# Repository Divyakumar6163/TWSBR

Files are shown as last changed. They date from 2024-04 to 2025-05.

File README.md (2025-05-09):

# Robofest 4.0 - Two Wheeled Self Balancing Robot

## Overview

This repository contains all the documentation, design files, and implementation details of a **Two-Wheeled Self-Balancing Robot** developed by students of **IIT Bhubaneswar** as part of **Robofest 4.0**.

The robot operates on the principle of an **inverted pendulum**, achieving dynamic stability using sensors, real-time data processing, and a PID control system. It combines **self-balancing** capabilities with **line-following** functionality, and features a **payload-carrying structure**.

## Table of Contents

* [Overview](#overview)
* [Robot Description](#robot-description)
* [Salient Features](#salient-features)
* [Mechanical Design](#mechanical-design)
* [Electronics and Control](#electronics-and-control)
* [Softwares Used](#softwares-used)
* [Block Diagrams](#block-diagrams)
* [Applications](#applications)
* [Team](#team)

## Robot Description

The robot uses two NEMA 23 stepper motors driven by a PID controller implemented on an **Arduino Nano**. An **MPU-6050** sensor detects the tilt and angular velocity. The robot balances itself by calculating real-time error values and adjusting motor outputs accordingly.

## Salient Features

* **Self-Balancing** using MPU-6050 and PID control
* **Payload capacity** of \~1kg
* **Line-following** using IR sensors
* **Adjustable height** using threaded rods
* **Symmetric aluminum frame** for better stability

## Mechanical Design

* 3-layer structure with aluminum plates (Top, Middle, Bottom)
* Fully threaded rods for height adjustment
* Custom motor mount flanges
* Center of gravity optimized for balance

## Electronics and Control

* **Microcontroller**: Arduino Nano
* **Sensors**: MPU-6050, IR Sensors
* **Actuators**: NEMA 23/17 Stepper Motors with TB6600/A4988 drivers
* **Protection**: Diodes, resistors, and capacitors for circuit stability

## Softwares Used

* **Arduino IDE**: PID logic, sensor reading, and motor control
* **SolidWorks**: CAD design of chassis
* **MATLAB**: PID tuning and simulation
* **KiCad & Fritzing**: PCB and circuit design
* **VS Code (Python + OpenCV)**: Code Editor
* **ANSYS**: Stress and vibration analysis

## Block Diagrams

#### Electronics Block Diagram
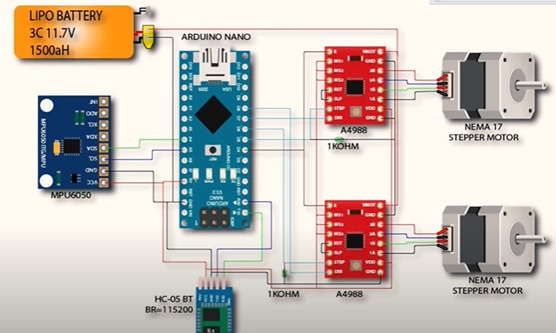
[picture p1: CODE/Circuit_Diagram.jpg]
Electronics Block Diagram


#### Flowchart
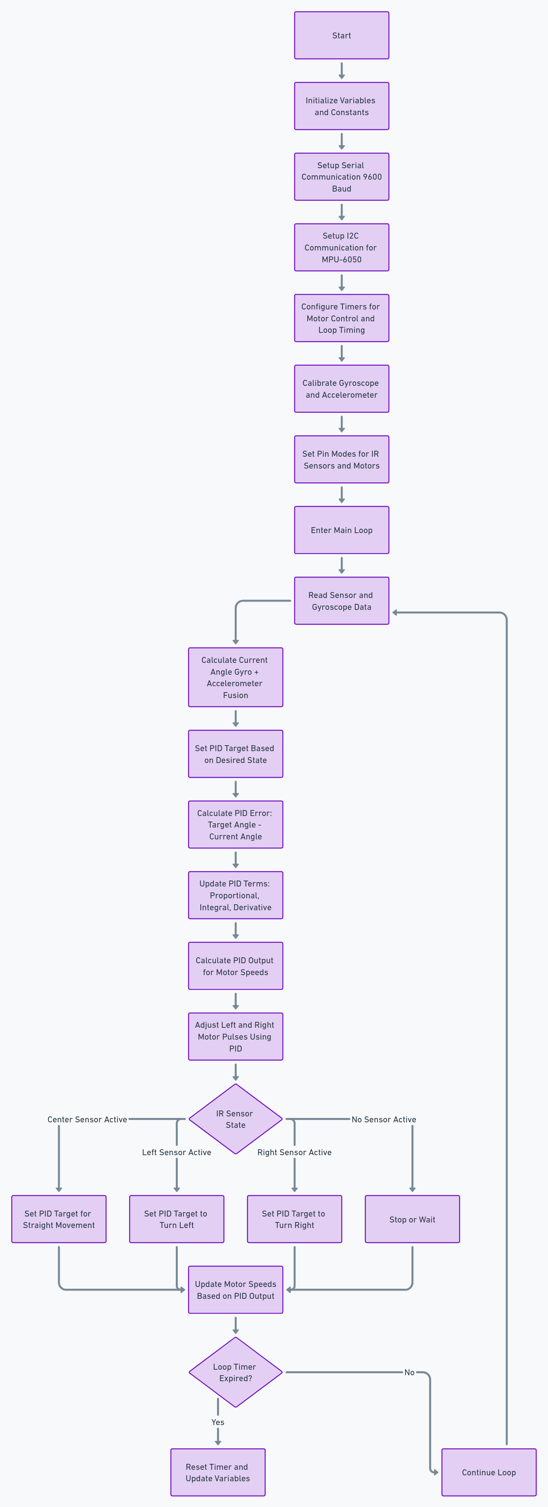
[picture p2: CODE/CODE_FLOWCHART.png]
Flowchart


## Applications

* Autonomous delivery systems
* Line-following warehouse bots
* Educational robotics
* Assistive mobility devices
* Smart surveillance platforms

## Team

**Team Members:**

* Ayush Gupta
* Divya Kumar
* Jiya Chakraborty
* Rachit Jain
* Vivek Singh

**Mentor:** Dr. Satyanarayan Panigrahi, Associate Professor, School of Mechanical Sciences

**Institute:** Indian Institute of Technology, Bhubaneswar

For full details, refer to the [REPORT.pdf](Reports/3.%20Grand_Finale/REPORT_finale.pdf) in the repository.

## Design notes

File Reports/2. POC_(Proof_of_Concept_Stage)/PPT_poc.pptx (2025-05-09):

## ROBOFEST 4.0

TWO WHEEL SELF BALANCING ROBOT
IIT BHUBANESWAR

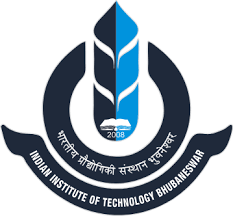
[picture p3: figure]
IIT Bhubaneswar - Wikipedia

## Robot Design

- Structural Framework: Designed frame using:
- 8 rods
- 3 Plates
- 2 side motor supports
- Battery and Container Design: For stability:
- Dedicated battery slot
- Baffles with holes
- Cantilever protrusions in baffles
- Strength and Durability: Thin ripples in the upper plate:
- Reduces thickness
- Increases strength

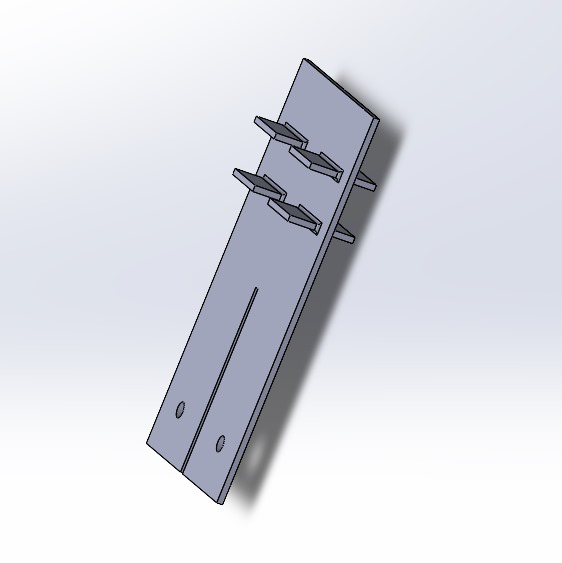
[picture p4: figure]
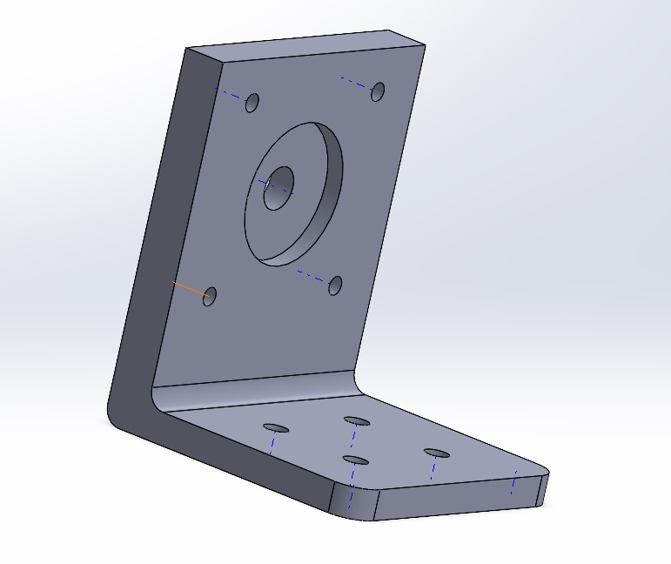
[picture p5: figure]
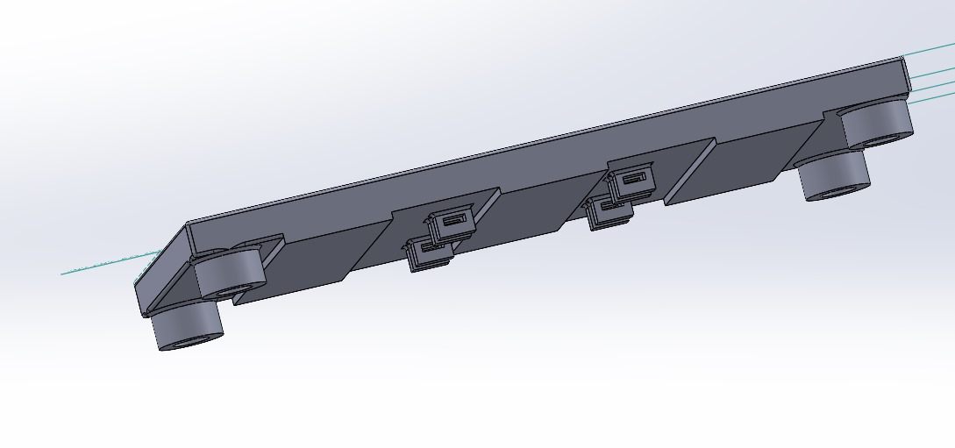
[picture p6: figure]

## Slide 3

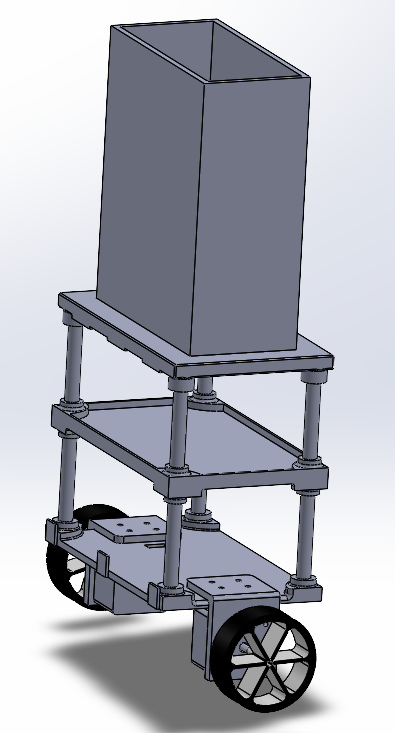
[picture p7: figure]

Fig.1:Isometric view of model.

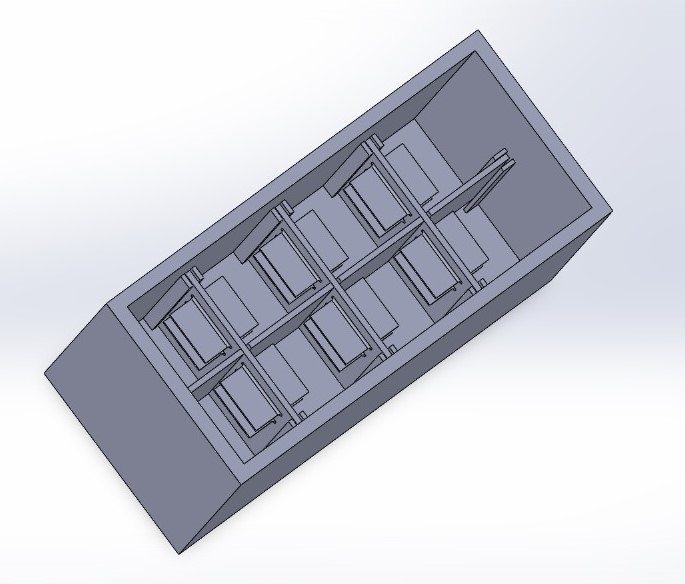
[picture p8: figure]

Fig.2: Beaker

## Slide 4

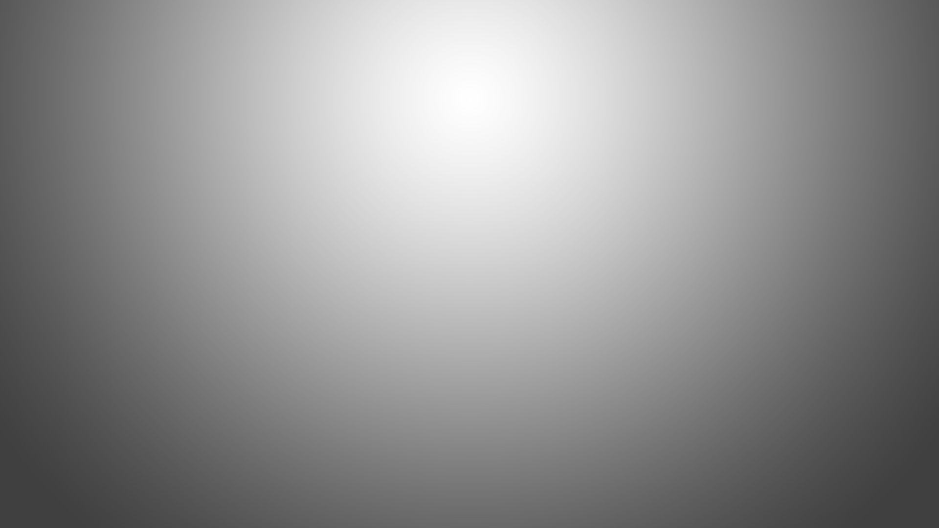
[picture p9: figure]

Total deformation analysis of the main structure and beaker

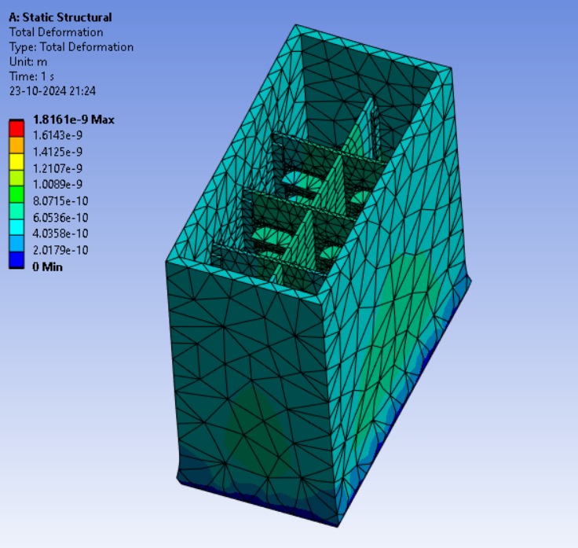
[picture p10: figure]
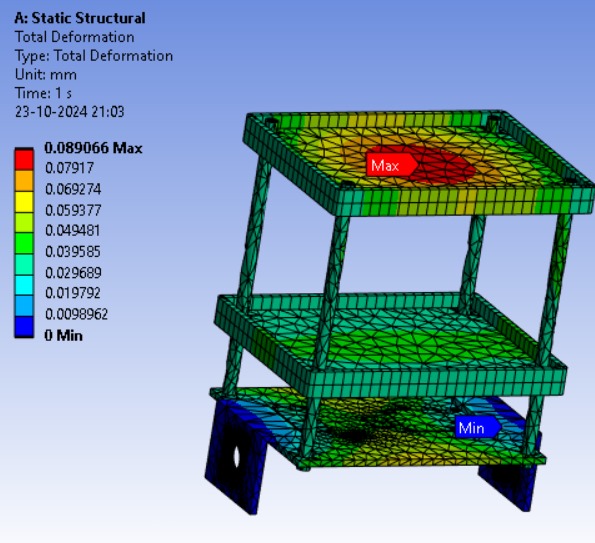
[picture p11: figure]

## Simulation

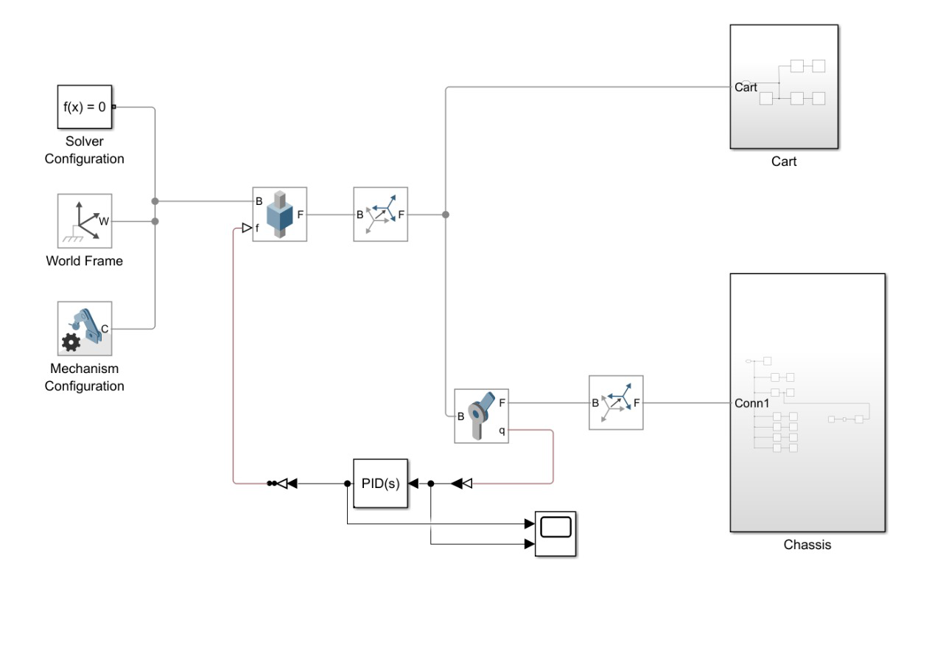
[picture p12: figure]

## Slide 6

The video below shows the simulation:

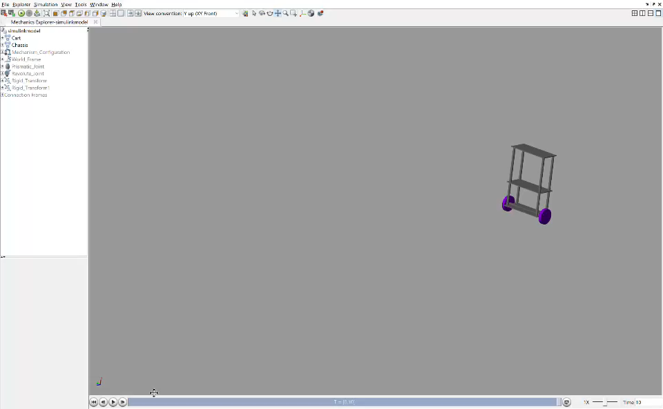
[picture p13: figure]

## Circuit

- Simple and Reproducible Circuit
- Arduino Nano (micro-controller):Arduino Nano is used as the microcontroller to run a PID control algorithm.
- Motor drivers to power the motors.
- Sensor Integration via Infrared Sensors (IRs)
- MPU 6050 for angular velocity & acceleration measurement

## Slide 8

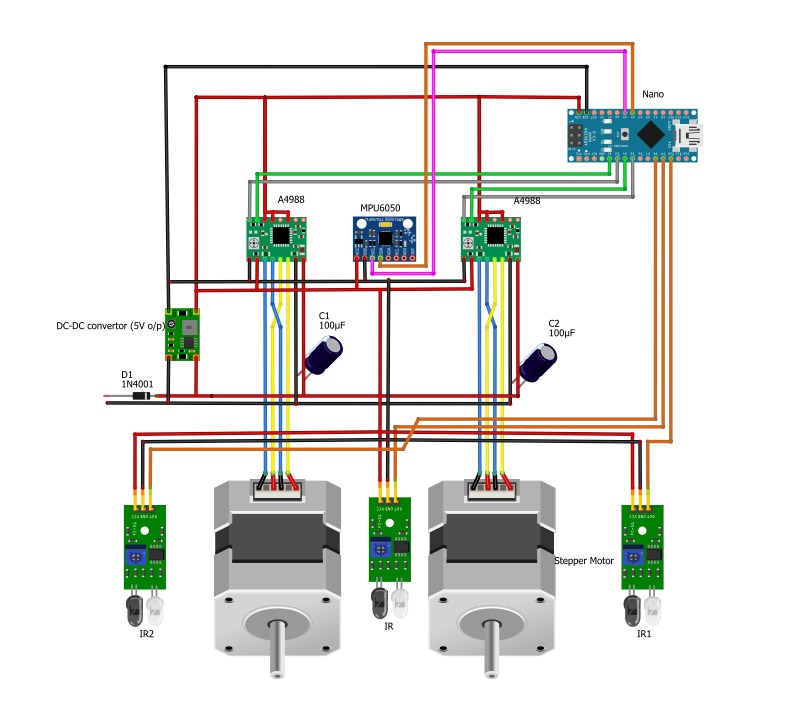
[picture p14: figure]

Complete circuit Diagram of our system

## Challenges Faced

- Tried different values to decide the interrupt time for powering the motors.
- Plotted different interrupt values to their to find the best values
- Tuning the setpoint values to achieve a speed where the robot maintains a balance.
- Multiple iterations to prevent low speeds and overshoot.
And many More…

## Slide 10

Thank You!
Team – IIT Bhubaneswar
Two wheel Self balancing robot

Mentor – Dr. Satyanarayan Panigrahi

Members:

1. Ayush Gupta
2. Divya Kumar
3. Jiya Chakraborty
4. Vivek Singh
5. Rachit Jain

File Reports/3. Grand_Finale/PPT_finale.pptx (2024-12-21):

## ROBOFEST 4.0

TWO WHEEL SELF BALANCING ROBOT
IIT BHUBANESWAR

IIT Bhubaneswar - Wikipedia

## Robot Design

- Structural Framework: Designed frame using:
- 8 rods
- 3 Plates
- 2 side motor supports
- Strength and Durability: Thin ripples in the upper plate:
- Reduces thickness
- Increases strength
- Container Design: To avoid splashing of water we have added:
- Baffles with holes
- Cantilever protrusions in baffles


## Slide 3


Fig.1:Isometric view of model.


Fig.2: Beaker

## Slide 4


Total deformation analysis of the main structure and beaker


## Simulation


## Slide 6

The video below shows the simulation:


## Circuit

- Simple and Reproducible Circuit
- ATMega 328 chip (micro-controller): It is used to run a PID control algorithm.
- Motor drivers to power the motors.
- Sensor Integration via Infrared Sensors (IRs)
- MPU 6050 for angular velocity & acceleration measurement

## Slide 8


Complete circuit Diagram of our system

## Challenges Faced

- Tried different values to decide the interrupt time for powering the motors.
- Plotted different interrupt values to their to find the best values
- Tuning the setpoint values to achieve a speed where the robot maintains a balance.
- Multiple iterations to prevent low speeds and overshoot.
And many More…

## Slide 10

Thank You!
Team – IIT Bhubaneswar
Two wheel Self balancing robot

Mentor – Dr. Satyanarayan Panigrahi

Members:

1. Ayush Gupta
2. Divya Kumar
3. Jiya Chakraborty
4. Vivek Singh
5. Rachit Jain

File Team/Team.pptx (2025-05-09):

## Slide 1

Two Wheeled Self Balancing Robot

Indian Institute of Technology Bhubaneswar

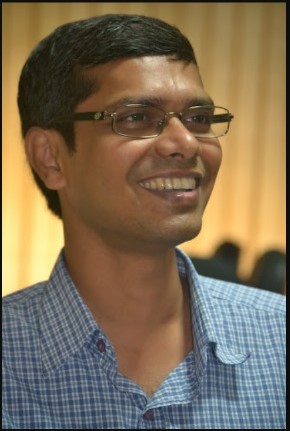
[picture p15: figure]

Dr. Satyanarayan Panigrahi

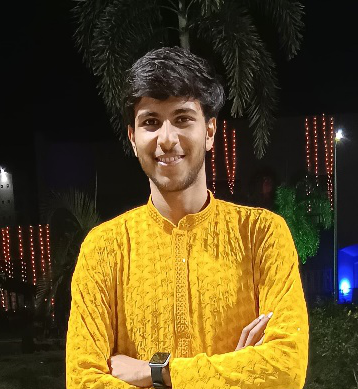
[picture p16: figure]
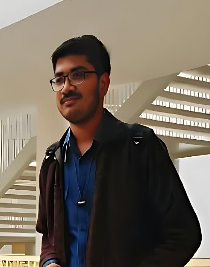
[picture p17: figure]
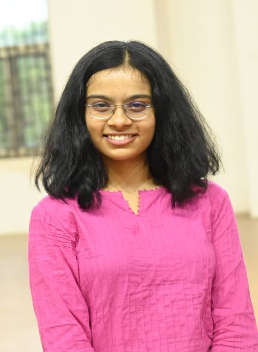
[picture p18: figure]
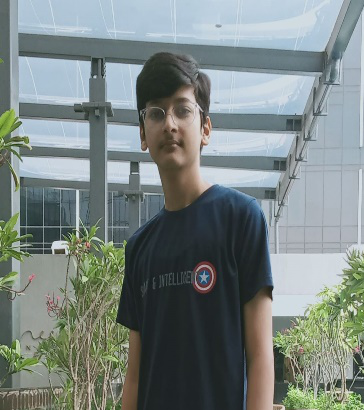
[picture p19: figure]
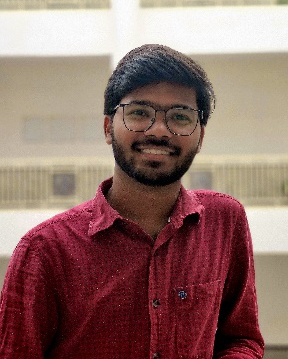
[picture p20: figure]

Vivek Singh

Divya Kumar

Ayush Gupta

Jiya Chakraborty

Rachit Jain

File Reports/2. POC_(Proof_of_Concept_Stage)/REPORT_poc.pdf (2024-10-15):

# ROBOFEST 4.0

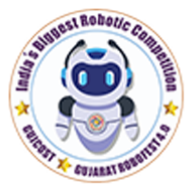
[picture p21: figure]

# TWO WHEEL SELF BALANCING ROBOT

Submitted By

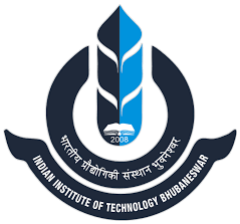
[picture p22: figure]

INDIAN INSTITUTE OF TECHNOLOGY,

# BHUBANESWAR

2024

# Contents:

1. Steps in the Working of the Robot | 3
2. List of Components used | 7
3. Software used & developed | 12
4. Additional Features in actual Robot-making | 20
5. Concurrence | 20
6. Other Description | 22
7. Photos | 23
8. Video Link | 23
9. About the Team | 24

## 1. Steps in the working of Robot

A. Description of Robot

A two-wheeled self-balancing robot operates on the principle of an inverted pendulum, using precise control to maintain an upright position. Its center of mass can shift away from the vertical due to uneven weight distribution, making it dynamically stable yet statically unstable. Built with a lightweight frame 3D-printed from durable PLA material, our robot features two NEMA 17 stepper motors that deliver smooth and stable movement. The control system, powered by an Arduino Nano, employs a PID control mechanism to maintain balance.
The robot is engineered to maintain its balance using a combination of elements involving sensors and a control algorithm. The detailed logical steps involved in the working of the robot have been mentioned below:

Initialization and Setup
To initialize the robot, start it from a standstill position, either lying down or standing upright with minimal vibrations. Upon powering up, the onboard MPU 6050 sensor begins calibration, indicated by a blinking LED on the Arduino Nano. If the robot is lying down, gently lift it to a vertical position once the calibration is complete. The robot will then automatically engage its balancing mechanism, using the calibrated sensor data to maintain an upright stance. After initialization, users can place additional loads or weights on top of the robot as needed, and it will adjust to maintain balance accordingly.

Data Acquisition

The microcontroller reads real-time data from the MPU 6050, which includes measurements from its built-in gyroscope and accelerometer. Using the Wire library, the microcontroller communicates with the MPU 6050 over the I2C protocol, ensuring quick data transmission while minimizing the number of required connections. The raw data obtained from the MPU 6050 is processed by the microcontroller, which performs calculations to derive the angular velocity and tilt angle. To achieve a more accurate and stable measurement of the tilt angle, a complementary filter is employed. This filter combines data from both the gyroscope and the accelerometer, leveraging the strengths of each sensor. The accelerometer helps correct long-term drift in the gyroscope data, while the gyroscope smooths out the noisy, short-term variations in the accelerometer readings. Together, they provide a more precise and stable tilt angle estimation, essential for effective balancing.

Error Calculation & Control Algorithm
In the control system, the error is determined by comparing the desired upright position, calibrated as 0 degrees, with the actual tilt angle measured by the sensors. This difference, known as the positional error, indicates how much the robot deviates from the vertical alignment. Additionally, the system calculates the rate of change of this error, which helps predict the robot's future movement trajectory and assess how quickly the tilt is changing.

The PID (Proportional-Integral-Derivative) controller uses this error to dynamically adjust the motor outputs and maintain balance. The Proportional component of the PID responds to the magnitude of the error, applying a corrective force that is directly proportional to the deviation from the upright position. The Integral component addresses accumulated errors over time, correcting small, persistent biases that could cause the robot to drift. More formally, it takes care of the steady state error. Lastly, the Derivative component considers the rate of change of the error, allowing the system to anticipate future deviations and make smoother, more stable adjustments.

Motor Control
The PID controller's output signals are sent to the motor driver, which adjusts the speed and direction of the stepper motors to maintain balance. Pulse Width Modulation (PWM) signals control the effective power supplied to the motors, allowing precise acceleration or deceleration. The system utilizes an Interrupt Service Routine (ISR) that executes every 20 microseconds, generating pulses to control motor speed and direction. This high-frequency, real-time pulse generation ensures smooth and responsive motor control, enabling the robot to quickly react to changes in tilt and maintain an upright position. The ISR handles pulse timing and motor direction switching, ensuring that corrective actions are applied accurately and consistently.

Feedback Loop
Errors are recalculated continuously and the updated values are sent to the control algorithm in real time to keep adjusting the motor movements accordingly. By continuously calculating and feeding the error into the PID controller, the robot can dynamically balance itself, ensuring real-time corrections to maintain its upright stance.

B. Electronics Description

The MPU6050 detects the tilt of the robot and sends this data to the Arduino Nano, which processes it to determine how to adjust the motors to keep the robot balanced. The Arduino Nano sends direction and step signals to the A4988 drivers, which then control the movement of the stepper motors. The motors adjust their movement to compensate for any imbalance detected by the MPU6050. The IR sensors provide additional functionality for line following. The DC-DC converter ensures that all components are powered correctly, and capacitors are used to stabilize the voltage supply for the motors.

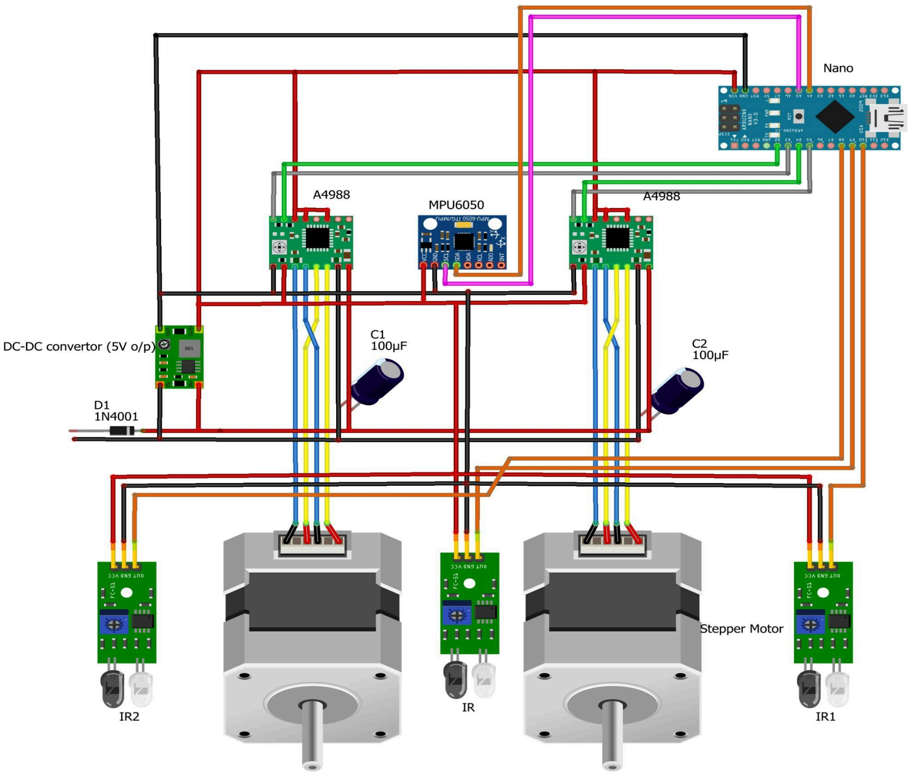
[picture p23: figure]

The above figure shows the circuitry employed to get the bot running.

C. Features

Payload Capacity:
Quite conveniently and without spilling anything, the robot is expected to be able to carry a payload effectively owing to the good design and sturdy construction of the frame. This battery case almost weighs 1200 grams with a well-balanced design that enables it to carry different types of objects comfortably. Such a feature comes in handy in the delivery and material handling applications where moving about with a load and still managing to keep in an upright position is a requirement.

Line Following with IR Sensors:

Infrared (IR) sensors are particularly important in line-following robots, as they allow the robot to detect and follow marked paths or lines. These sensors enable the robot to automatically adjust its movement based on the detected lines. This capability is especially useful in applications where the robot needs to operate in confined areas, such as storage facilities or assembly lines, where robots perform tasks as part of a larger process.

Autonomous Self-Balancing:
Based on the inverted pendulum structure of the robot, self-balancing can be achieved automatically with the assistance of the user being limited. The MPU 6050, which is one of the sensors installed in the robot system, detects the activities such as angle tilt and the speed at which the tilt changes or angular velocity and feeds those to the PID controller.

## 2. List of Components used:

All our components except the wheels were 3D printed to strike the balance between the payload carrying capacity and the weight of the robot itself.

A. Mechanical Components

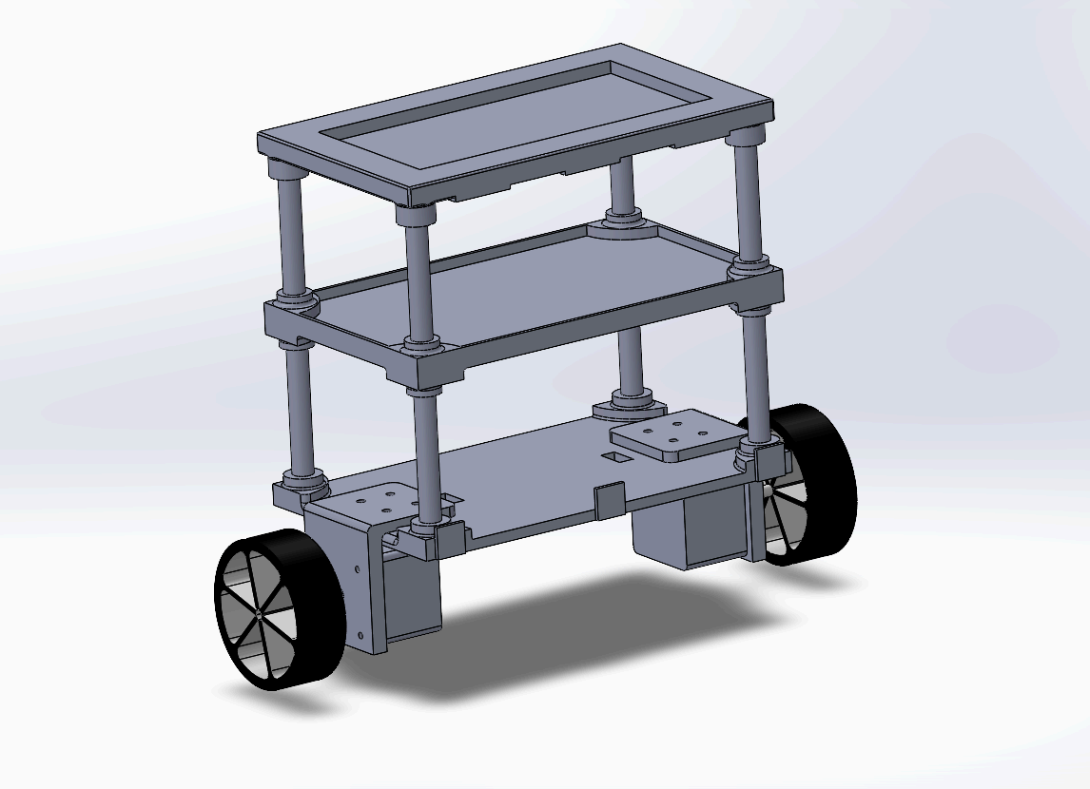
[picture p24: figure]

Fig 1 Complete Assembly
The above figure shows the complete detailed assembly of our robot.

Plates(x3)
Our model consists of three plates.

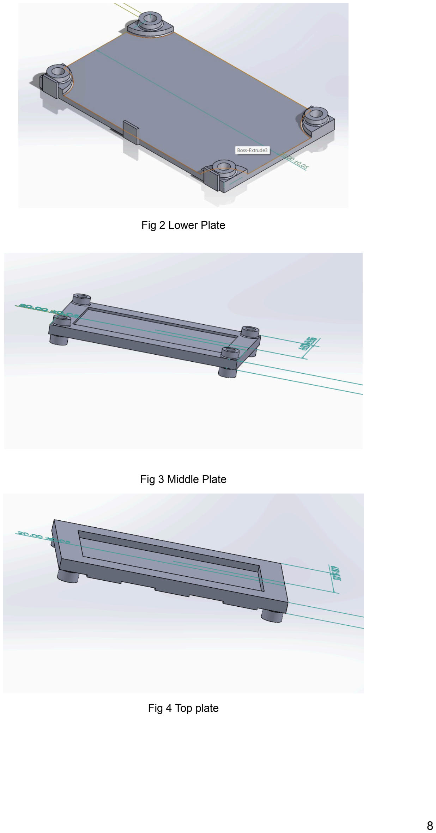
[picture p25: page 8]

Fig 2 Lower Plate

Fig 3 Middle Plate

Fig 4 Top plate

Rods ( x8 )
Four rods would connect the upper and middle plates while the rest would connect the middle and lowermost one.

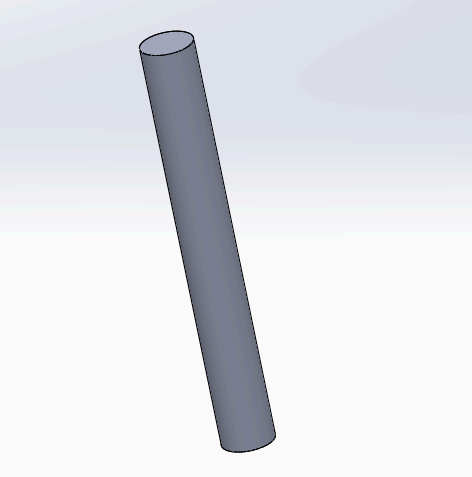
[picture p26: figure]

Fig 5 Rod
Wheels
Plastic wheels were deemed suitable for the bot as they were lightweight and capable of handling the torque from the motor. Wheels of appropriate dimensions were chosen for this purpose to give the required ground clearance.

Nuts and Bolts
Nuts and bolts were used to attach the motors and the cubical box to the legs securely.
B. Electronics component

Arduino Nano(Microcontroller)
The microcontroller that we have used in our robot is the arduino nano. It features 22 digital I/O pins, 8 analog inputs, and operates at 5V with a clock speed of 16MHz. It can be programmed via the USB interface using the Arduino IDE. Its small size and versatility make it suitable for embedded systems and space-constrained applications.

Motor Driver
A4988 stepper motor driver has been used to ensure it’s compatibility with the stepper motor that we have decided to use for our robot.

Motor

The NEMA17 stepper motor has been chosen for its precision and high torque. This motor allows for accurate positioning and speed control, making it ideal for applications that require fine control over movement.

IR sensor module
In order to enable the robot to follow a path, IR sensors have been used in the circuitry which detects the line and accordingly moves it forward such that it maintains the route that is intended to be followed.

Voltage Regulators
Voltage regulators (LM2596 DC-DC Step down converter) ensure that constant voltage is supplied to the electronic components even in the case of slight fluctuations in the voltage supply and prevent any kind of damage.

Resistors and Capacitors
Resistors help in limiting the amount of current that flows into various electronic components. Capacitors smooth voltage fluctuations and filter noise in power supplies, especially near stepper motor drivers, ensuring stable operation. They also reduce electromagnetic interference (EMI) generated by switching currents, improving motor performance and accuracy.

Diodes
Diodes protect circuits by blocking reverse current flow and ensuring unidirectional current, safeguarding sensitive components from damage.
C. Tools and Equipment

3D printer
One of the major equipment that we have used to manufacture the robot at the proof of concept stage is the 3D printer. We first designed our model in solidworks and then printed the components. Care was taken to ensure that the design consists of parts which can be assembled post printing. This, though might seem insignificant, was essential to ensure that the printing process happens seamlessly and without any cut-offs due to overloading.

Pliers, Screwdrivers etc.
These tools were used to tighten the nuts and bolts securely.

Drill machine and Drill Bits
The machine was used to slightly widen the holes to fit the bolt exactly and securely.

Soldering Iron
Soldering iron fit the naked wires to their correct spots and ensured proper conductivity.

Multimeter
Multimeter is used to adjust the motor driver current, ensuring accurate power delivery to the motors, and to check wiring continuity for proper circuit functionality.

Electro - Mechanical Component


Fig 5 1.8° 42mm Hybrid Stepper Motor-NEMA17
Stepper motor was used to convert the electrical signals to mechanical output. Stepper motors offer a variety of advantages over DC motors and servo motors. They do not need an encoder (which is required in DC motors) and overall precision is easier to achieve using stepper motors. The step pulse frequency makes it easier to control the motor which is essential to adjust not just the speed of the robot but the acceleration/deceleration depending on the tilt error.

## 3. Software Used and Developed

The software used for writing and developing the code is the Arduino IDE. (https://www.arduino.cc/en/software) Additionally, SolidWorks (https://www.solidworks.com/) was utilized for designing the mechanical components of the robot, enabling the creation of detailed 3D models and simulations. The following sections present the code developed specifically for our robot, with comments included to ensure smooth readability and understanding.

Code:

// Include Wire.h library for communication

#include <Wire.h>

// pins

const int dirPin1 = 5;

const int stepPin1 = 4;

const int dirPin2 = 3;

const int stepPin2 = 2;

const int irSensorPin = 9;

const int irSensorPin1 = 8;

const int irSensorPin2 = 10;

float Kp = 14;

float Ki = 2;

float Kd = 2;

float turnRate = 30;

float maxSpeed = 15;

float angleGyro, angleAcc, angle, balancePidSetpoint;

float pidErrorTemp, pidIMem, pidSetpoint, pidOutput, pidLastDError;

float pidOutputLeft, pidOutputRight;

int leftMotor, throttleLeftMotor, throttleCounterLeftMotor, throttleLeftMotorMemory;

int rightMotor, throttleRightMotor, throttleCounterRightMotor,

throttleRightMotorMemory;

int receiveCounter;

// MPU-6050 I2C address (0x68)

int gyroAdd = 0x68;

int accCalibration = -410;

long gyroYawCalibration, gyroPitchCalibration;

int gyroPitchData, gyroPitchData, accelerometerData;

byte start, inputByte;

unsigned long loopTimer;

// Initial setup runs only at the start

void setup()

{

Serial.begin(9600);

Wire.begin();

// Setting I2C clock speed to 400kHz

TWBR = 12;

// To create a timer of 20us

TCCR2A = 0;

TCCR2B = 0;

TIMSK2 |= (1 << OCIE2A);

TCCR2B |= (1 << CS21);

OCR2A = 39;

TCCR2A |= (1 << WGM21);

// Start MPU-6050

Wire.beginTransmission(gyroAdd);

Wire.write(0x6B);

Wire.write(0x00);

Wire.endTransmission();

// Setting full scale of the gyro to +/- 250 degrees per second

Wire.beginTransmission(gyroAdd);

Wire.write(0x1B);

Wire.write(0x00);

Wire.endTransmission();

// Setting full scale of the accelerometer to +/- 4g.

Wire.beginTransmission(gyroAdd);

Wire.write(0x1C);

Wire.write(0x08);

Wire.endTransmission();

// Setting filtering to improve the raw data.

Wire.beginTransmission(gyroAdd);

Wire.write(0x1A);

Wire.write(0x03);

Wire.endTransmission();

pinMode(stepPin1, OUTPUT);

pinMode(dirPin1, OUTPUT);

pinMode(stepPin2, OUTPUT);

pinMode(dirPin2, OUTPUT);

pinMode(13, OUTPUT);

pinMode(irSensorPin, INPUT);

pinMode(irSensorPin1, INPUT);

pinMode(irSensorPin2, INPUT);

calibrateGyro();

loopTimer = micros() + 4000;

}

// Main program loop

void loop()

{

int IRS = digitalRead(irSensorPin);

int IRSL = digitalRead(irSensorPin1);

int IRSR = digitalRead(irSensorPin2);

if (IRS)

{

inputByte = 0x04;

receiveCounter = 0;

}

if (receiveCounter <= 25)

receiveCounter++;

else

inputByte = 0x00;

// Angle calculations

Wire.beginTransmission(gyroAdd);

Wire.write(0x3F);

Wire.endTransmission();

Wire.requestFrom(gyroAdd, 2);

accelerometerData = Wire.read() << 8 | Wire.read();

accelerometerData += accCalibration;

if (accelerometerData > 8200) accelerometerData = 8200;

if (accelerometerData < -8200) accelerometerData = -8200;

angleAcc = asin((float)accelerometerData / 8200.0) * 57.296;

if (start == 0 && angleAcc > -0.5 && angleAcc < 0.5)

{

angleGyro = angleAcc;

start = 1;

}

Wire.beginTransmission(gyroAdd);

Wire.write(0x43);

Wire.endTransmission();

Wire.requestFrom(gyroAdd, 4);

gyroPitchData = Wire.read() << 8 | Wire.read();
gyroPitchData = Wire.read() << 8 | Wire.read();

gyroPitchData -= gyroPitchCalibration;

angleGyro += gyroPitchData * 0.000031;

gyroPitchData -= gyroYawCalibration;

// angleGyro -= gyroPitchData * 0.0000003;

// Complementary Filter to correct the drift of the gyro angle

angleGyro = angleGyro * 0.9996 + angleAcc * 0.0004;

pidCalculation();

movementCalculation();

controlMotors();

// to ensure every loop is exactly 4ms

while (loopTimer > micros());

loopTimer += 4000;

}

// to calibrate gyro settings

void calibrateGyro()

{

for (receiveCounter = 0; receiveCounter < 500; receiveCounter++)

{

if (receiveCounter % 15 == 0)

digitalWrite(13, !digitalRead(13));

Wire.beginTransmission(gyroAdd);

Wire.write(0x43);

Wire.endTransmission();

Wire.requestFrom(gyroAdd, 4);

gyroYawCalibration += Wire.read() << 8 | Wire.read();
gyroPitchCalibration += Wire.read() << 8 | Wire.read();

delayMicroseconds(3700);

}

gyroPitchCalibration /= 500;

gyroYawCalibration /= 500;

}

// PID calculations

void pidCalculation()

{

pidErrorTemp = angleGyro - balancePidSetpoint - pidSetpoint;

if (pidOutput > 10 || pidOutput < -10)

pidErrorTemp += pidOutput * 0.015;

pidIMem += Ki * pidErrorTemp;

if (pidIMem > 400)

pidIMem = 400;

else if (pidIMem < -400)

pidIMem = -400;

// Calculate the PID output value

pidOutput = Kp * pidErrorTemp + pidIMem + Kd * (pidErrorTemp - pidLastDError);

if (pidOutput > 400)

pidOutput = 400;

else if (pidOutput < -400)

pidOutput = -400;

pidLastDError = pidErrorTemp;

if (pidOutput < 5 && pidOutput > -5)

pidOutput = 0;

// if angle is greater than 30 stop the bot

if (angleGyro > 30 || angleGyro < -30 || start == 0)

{

pidOutput = 0;

pidIMem = 0;

start = 0;

balancePidSetpoint = 0;

}

}

// Movement control calculations for LRFB-(Left,Right,Front,Back)

void movementCalculation()

{

pidOutputLeft = pidOutput;

pidOutputRight = pidOutput;

// Turn robot leftward

if (inputByte & B00000001)

{

pidOutputLeft += turnRate;

pidOutputRight -= turnRate;

}

// Turn robot rightward

if (inputByte & B00000010)

{

pidOutputLeft -= turnRate;

pidOutputRight += turnRate;

}

// Move forward

if (inputByte & B00000100)

{

if (pidSetpoint > -2.5)

pidSetpoint -= 0.05;

if (pidOutput > maxSpeed * -1)

pidSetpoint -= 0.005;

}

// Move backward

if (inputByte & B00001000)

{

if (pidSetpoint < 2.5)

pidSetpoint += 0.05;

if (pidOutput < maxSpeed)

pidSetpoint += 0.005;

}

// restore settings

if (!(inputByte & B00001100))

{

if (pidSetpoint > 0.5)

pidSetpoint -= 0.05;

else if (pidSetpoint < -0.5)

pidSetpoint += 0.05;

else

pidSetpoint = 0;

}

if (pidSetpoint == 0)

{

if (pidOutput < 0)

balancePidSetpoint += 0.0010;

if (pidOutput > 0)

balancePidSetpoint -= 0.0010;

}

}

// Motor control pulse calculations

void controlMotors()

{

if (pidOutputLeft > 0)

pidOutputLeft = 405 - (1 / (pidOutputLeft + 9)) * 5500;

else if (pidOutputLeft < 0)

pidOutputLeft = -405 - (1 / (pidOutputLeft - 9)) * 5500;

if (pidOutputRight > 0)

pidOutputRight = 405 - (1 / (pidOutputRight + 9)) * 5500;

else if (pidOutputRight < 0)

pidOutputRight = -405 - (1 / (pidOutputRight - 9)) * 5500;

// pulse time calculation for the left and right stepper motor controllers

if (pidOutputLeft > 0)

leftMotor = 400 - pidOutputLeft;

else if (pidOutputLeft < 0)

leftMotor = -400 - pidOutputLeft;

else

leftMotor = 0;

if (pidOutputRight > 0)

rightMotor = 400 - pidOutputRight;

else if (pidOutputRight < 0)

rightMotor = -400 - pidOutputRight;

else

rightMotor = 0;

throttleLeftMotor = leftMotor;

throttleRightMotor = rightMotor;

}

ISR(TIMER2_COMPA_vect)

{

// Left motor pulse calculations

throttleCounterLeftMotor++;

if (throttleCounterLeftMotor > throttleLeftMotorMemory)

{

throttleCounterLeftMotor = 0;

throttleLeftMotorMemory = throttleLeftMotor;

if (throttleLeftMotorMemory < 0)

{

PORTD &= 0b11110111;

throttleLeftMotorMemory *= -1;

}

else

PORTD |= 0b00001000;

}

else if (throttleCounterLeftMotor == 1)

PORTD |= 0b00000100;

else if (throttleCounterLeftMotor == 2)

PORTD &= 0b11111011;

// right motor pulse calculations

throttleCounterRightMotor++;

if (throttleCounterRightMotor > throttleRightMotorMemory)

{

throttleCounterRightMotor = 0;

throttleRightMotorMemory = throttleRightMotor;

if (throttleRightMotorMemory < 0)

{

PORTD |= 0b00100000;

throttleRightMotorMemory *= -1;

}

else

PORTD &= 0b11011111;

}

else if (throttleCounterRightMotor == 1)

PORTD |= 0b00010000;

else if (throttleCounterRightMotor == 2)

PORTD &= 0b11101111;

}

## 4. Additional Features in Actual Robot-Making

An additional middle plate has been added to the model, keeping future enhancements in mind. The connections have been designed to allow easy integration of a Bluetooth module with minimal wiring, enabling remote control of the robot. This flexible design ensures that more functionalities can be added without significant changes.

## 5. Concurrence / Deviation from stage 1 Report

During the design and development of the robot, certain adjustments were deemed essential to the initial component selection to better meet the project's requirements. These deviations were driven by the need for enhanced precision, stability, and adherence to the primary objectives. The major changes and their justification can be enumerated as follows:

### 1. Using Stepper Motor Instead of DC Motor:

Precise Position Control:Since DC motors work with intermittent rotation, while stepper motors are capable of discrete singular steps this affords precise control over their position, making them ideal for applications where accuracy is crucial, such as balancing a robot. A stepper corresponds to a precise rotation therefore, adjustments to the robot position would be carried out to correct an imbalance.

Better Torque at Low Speeds:Stepper motors have no appreciably negative effects on a minor voltage fluctuation that can potentially lead to speed drift in DC motors. Since the rotation of a stepper motor depends on the number of input pulses rather than the voltage, the result is constant speed, an important factor in the stable and reliable performance of a self-balancing robot.

No Speed Drift Due to Voltage Fluctuation: Stepper motors are not affected by minor voltage fluctuations that can cause speed drift in DC motors. Since the rotation of a stepper motor is controlled by the number of input pulses rather than the voltage, the speed remains consistent, which is essential for reliable and stable performance in a self-balancing robot.

### 2. Using Arduino Nano Instead of ESP32:

No External Controls Allowed: Since it was required for the project to have no need for any external control, Arduino Nano was chosen instead of ESP32. Even though ESP32 provides WiFi and Bluetooth connectivity, it was not necessary for the execution of the desired autonomous function without oversight. The Arduino Nano is, in this case, the simpler and compact Arduino platform, while still efficient in the handling of controlling tasks involved in this project.

### 3. Inclusion of IR Sensors for Autonomous Movement:

Enhanced Navigation Capability: To support autonomous movement, IR sensors were added to the design to enable line-following functionality. These sensors detect contrasts on the surface and provide data to the control system, allowing the robot to track a predefined path. This addition makes the robot capable of navigating complex environments independently, improving its versatility for tasks like material transport, assembly line operations, and competitive robotics scenarios.

## 6. Other Description

One of the key techniques used in building the robot was opting for an Interrupt Service Routine (ISR) over the standard AccelStepper library. This choice was driven by several critical factors:

1. Precision and Control: The ISR is triggered every 20 microseconds, allowing for precise and consistent pulse generation for the stepper motors. The AccelStepper library, while convenient, can introduce overhead that may lead to slight delays or inconsistencies, especially when precise timing is critical. By using an ISR, we ensured that motor control tasks were executed at specific, tightly controlled intervals, maintaining the robot's stability and accuracy.
2. Real-Time Response: With the ISR operating at a high frequency, the robot can make rapid adjustments in response to changes in tilt or angular velocity detected by the MPU 6050. This real-time response is essential for maintaining balance, as it allows the system to react quickly and predictively without lag. By contrast, the standard library might introduce latency, reducing the system’s ability to respond immediately.
3. Efficient Use of Processing Resources: Since the ISR handles motor control directly, it bypasses the higher-level abstractions of the library, resulting in more efficient code execution. The Arduino Nano loop function, which runs every 4 milliseconds, can then focus on other tasks such as reading sensor data, performing PID calculations, and handling communication, without being burdened by motor control logic. This division of tasks ensures smooth and uninterrupted operation of the system.

Moreover, we used the register values of the Arduino Nano to configure specific parameters, including the SCL (Serial Clock Line) frequency and conditions under which the ISR is called. By directly setting these registers, we could fine-tune the communication speed between the microcontroller and sensors, ensuring fast and reliable data acquisition. This low-level control also allowed for precise timing adjustments for the ISR, which was essential for maintaining consistent motor performance and stability.

## 7. Photos:



## Video Link: https://drive.google.com/file/d/1Eq4Ps5q3Ih3qkz_DgO-prheO

2mjEV1y3/view?usp=sharing (https://drive.google.com/file/d/1Eq4Ps5q3Ih3qkz_DgO-prheO2mjEV1y3/view?usp=sharing)

## 8. ABOUT THE TEAM

Mentor:

Dr. Satyanarayan Panigrahi
Associate Professor
School of Mechanical Sciences

Ph.D. Mechanical (Technical Acoustics) - 2007 Indian Institute of Science, Bangalore

Research Interests

Technical Acoustics, Industrial Noise Control, Automotive noise control, Acoustic based Condition Monitoring of Machines, and Musical Acoustics.

Team Members:

1. Ayush Gupta
2. Divya Kumar
3. Jiya Chakraborty
4. Rachit Jain
5. Vivek Singh

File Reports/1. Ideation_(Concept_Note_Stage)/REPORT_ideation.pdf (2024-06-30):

# ROBOFEST 4.0

## TWO WHEEL SELF BALANCING ROBOT

Submitted By


### Indian Institute of Technology Bhubaneswar

2024

## CONTENTS

## OVERVIEW

A Two-Wheel Auto-Balancing Robot (more commonly known as TWABR) employs a pair of vertically aligned wheels to achieve its primary objective of preserving equilibrium and avoiding tipping over. The wheels are driven by two motors coupled to each of them. The motors can be of a DC nature and are controlled by electrical signals using a control system based on the inclination reading and the velocity of their gravity centre. Its operation is similar to the classic inverted pendulum system. The objective of this project is to create and deploy a self-stabilising robot utilising an ESP 32 microcontroller, an MPU6050 accelerometer, a gyroscope sensor, and an L298N motor driver. The report provides a detailed description of the components that are required and how they are used. The motivation for working with the TWSBR came from the fact that it’s an interesting robot to control, not only because of its unstable and non-linear nature but also because of its application outside the academic environment.

## AIM

To make a two-wheeled auto-balancing robot which is a free-standing robot that maintains its balance. The robot will balance on two wheels and use two sensors, a gyroscope and feedback to determine the current angular position versus the desired angular position. No readymade kits/chassis are allowed. No external controls are allowed.

## COMPONENTS

1). Structure Components:

Components | Manufacturer
Plates | 3D-Printed using Institute lab facilities
Wheel | Electronics Comp.
Shaft | Xinjinghua Shaft
Rods | Ambica Steel
Acrylic Sheets for Casing | 3D-Printed using Institute lab facilities
Nut Bolt | Usha Fasteners

2). Electronics Components:

Components | Manufacturer
Microcontroller | ESP 32
Motor Driver (L298N) | Robodo

11.1 Li-Po Battery | MatLogix Technologies Private Limited
Motor | Robu
MPU6050 Gyroscope sensor | Electronic Spices (India)

### Description of Components:

### 1. Plates & Rods:

The design consists of three plates and four rods. The bottom two plates serve the purpose of providing space for all the electronic and mechanical components, while the topmost plate is intended for transportation purposes, carrying the required payload. The rods provide support to the robot's structure, as the plates are connected to these rods.

### 2. Wheels & Shaft:

There are 2 wheels which will handle all the load and will be transmitted to the main body by the bearings. The shaft is attached to the motor to drive the wheel, there are 2 shafts for each wheel.

### 3. Acrylic Sheets for Casing:

Two acrylic sheets will encase the electronic and mechanical parts, attached to the lower two plates from the front and back, to avoid and minimize any damage. Acrylic was chosen for its lightweight nature and its ability to be easily crafted into the desired dimensions.

### 4. Nut Bolt:

These are utilised to provide robust mechanical joints and secure the structure of the robot in place.

5. 11.1 Li-Po Battery:
The 11.1V 3S 3300mAh 40C Lipo Battery with XT60 Connector is a 3s1p battery pack with a nominal Voltage of 11.1V. This battery pack has 3 cells connected in series with a capacity of 40 C continuous discharge. The nominal capacity of the battery pack is 3300mah.

### 6. ESP 32 (Microcontroller):


https://robu.in/wp-content/uploads/2022/07/ESP32D-23.jpg
The ESP32, built around the Tensilica Xtensa LX6 microprocessor, features dual-core and single-core variations with clock frequencies up to 240 MHz. It encompasses 34 digital input/output pins (16 of which support PWM output), 12-bit ADC with 18 channels, 2 8-bit DAC channels, touch sensor capabilities, and an integrated 2.4 GHz Wi-Fi and Bluetooth 4.2/BLE module. The ESP32 also includes SPI, I2C, and UART interfaces, a micro-USB connection, a power jack, and a built-in reset button. Additionally, the board has a flash memory capacity ranging from 2MB to 16MB, facilitating extensive data storage and processing capabilities. It includes a CP2102 USB-to-UART bridge for easy programming and debugging. The ESP32 is designed to facilitate advanced IoT applications and can be powered via USB, AC-to-DC adapter, or battery, enabling versatile deployment across various projects.

### 7. L298N Motor Driver:


https://images.app.goo.gl/XWcTdJpQxTTyAbzAA
L298N is a motor driver which can control the speed and direction of up to two DC motors. This motor driver is one of the cheapest and easiest ways to control DC motors. One more advantage is that it can control a stepper motor as well. The main central processing unit of the L298N motor driver is the L298N chip which comes with a big, black heat sink. The L298N IC is a dual-channel H-bridge motor driver which can run two DC motors simultaneously. This makes the L298N motor driver ideal for two and four-wheeled projects.

### 8. MPU6050 (accelerometer & gyroscope sensor):


https://images.app.goo.gl/5Y3bpCs89SrEFoXF7
The MPU6050 is a Micro-Electro-Mechanical System (MEMS) that consists of a 3-axis Accelerometer and a 3-axis Gyroscope inside it. This helps us to measure acceleration, velocity, orientation, displacement and many other motion-related parameters of a system or object. This module also has a (DMP) Digital Motion Processor inside it which is powerful enough to perform complex calculations and thus free up the work for Microcontroller.

### 9. MOTOR:


https://bit.ly/4boZ7ZB
This 12V DC motor provides a torque of 5 Kg-cm, making it suitable for heavy-duty applications. With a rotational speed of 1000 RPM, it offers both power and efficiency. The motor features a 6mm shaft, designed for durability and stability. The geared mechanism enhances its torque capabilities, making it ideal for automotive and industrial tasks.

## MECHANISM

This section of the report aims to give a holistic view of how the two-wheeled balancing robot will be realised and the concepts that we plan to employ to achieve our objective.
The mechanism of a self-balancing robot constitutes the integration of several data that is acquired by the utilisation of a variety of components as stated above.
It is based on the physics of an inverted pendulum.

Inverted Pendulum mechanism:

The inverted pendulum mechanism has been recognized as an extremely complicated mechanism to control as a part of control engineering. The reason behind this perpetual challenge is attributed to the non-linear of the mechanism.


The figure above shows an inverted pendulum with a cart.
A pendulum of this kind will simply fall over if not displaced slightly.

To solve this further, the mathematical model obtained is:

Mẍ + bẋ + mẍ + mlӪcosϴ − mlϴ

˙

2
sinϴ = F

IӪ + ml

2Ӫ + mglsinϴ = − mlẍcosϴ

Source: 2014 International Conference on Robotics and Emerging Allied Technologies in Engineering

The above equations in linear form would be:

(I + ml

2
)

d

2φ

dt

2 − mglφ = ml d

2
x
dt

2

(M + m)

d

2
x
dt

2 + b

dx

dt − ml d

2φ

dt

2 = u

The state space models can be obtained from the equations. Then simulation software will be used to detect and confirm that without control, this system will indeed be rendered unstable.

The Robot
To be able to describe the orientation of the robot under different circumstances and to be able to identify its stable configuration, we need to define some angles and distances.


Fig. 1: XOZ modeling

Fig2: XOY modeling


Fig. 3: (a)Describes the stable state of the two-wheeled self-balancing robot. (b) Indicates the robot leans to the right.
(c) Demonstrates the robot leans to the left.

Establishing the dynamic model in this project involves the physical principles of the Lagrangian equation and Newton’s Second Law in three-dimensional motion.

We would arrive at a result by a deep analysis of the relationship between the forces and motors’ voltage through a series of mathematical derivatives in the X-O-Y and X-O-Z directions.

## CALCULATION


a) Calculation of Center of Mass (COM)


b) Calculation of Torque and RPM

## PID Control

To maintain the equilibrium and stability of the robot, it is necessary to generate a suitable control signal that drives the motors in the proper direction and at the proper speed. We will accomplish this by employing a well-known control loop algorithm called a PID controller.
PID stands for Proportional Integral Derivative. The controller has three control actions:

Proportional Control (Kp): Multiplies current error by Kp to provide immediate response proportional to error magnitude.
Integral Control (Ki): Accumulates errors over time and adjusts control output to eliminate steady-state errors using Ki.
Derivative Control (Kd): Calculates error rate of change and adjusts control to anticipate system behavior, contributing to stability with Kd.

Its control architecture is feedback, where the input to the controller is the system error signal e(t). It yields an error value by calculating the difference between a point of reference and an actual point.
The output of a PID controller, which is equal to the control input, is calculated in the time domain from the feedback error as follows:

u(t) = Kp. e(t) + Ki∫e(t)dt + Kd

de(t)
dt

Particularly in the derivative term, PID controllers are susceptible to measurement noise that can amplify high-frequency noise and result in erroneous control actions. In addition, the output of MPU6050 signals is frequently tainted with noise. To mitigate this, a Kalman filter is implemented, which focuses primarily on the issue of noise sensitivity in PID controllers. The Kalman filter improves the precision of state estimations and assists in mitigating the detrimental impacts of measurement noise on the control system through the reduction of sensor noise.
Here is how this filter works and its role in the control system.
- State Estimation: Kalman filter processes accelerometer and gyroscope data to estimate tilt angle, angular velocity, and possibly angular acceleration.
- Sensor Fusion: Combines accelerometer and gyroscope data for more accurate state estimation than either sensor alone.
- Noise Reduction: Mitigates sensor noise effects by incorporating statistical models into the estimation process.

- Dynamic System Model: Integrates the dynamic model of the system to describe state variable evolution based on control inputs and system dynamics.
- Feedback for Control: Provides estimated state feedback to the PID controller, guiding control actions to drive the robot towards the desired state, such as an upright position.

## CAD MODEL

*ALL THE CAD MODELS ARE MADE ON THE SOLIDWORKS SOFTWARE

Two Wheeled Self Balancing Robot CAD Model


Fig 1: Final Design of CAD Model along with its stages. https://github.com/Divyakumar6163/TWSBR/blob/main/CAD%20MODEL/TWSBR.SLDASM

This is the overall CAD model that includes every part we will be using for the two-wheeled self-balancing robot. The model is 20 cm tall, 10 cm wide(wheels included), and 15 cm long. After analyzing a number of designs, we ultimately developed the one seen above. In the final model, we placed the battery and its casing underneath the last plate instead of the original placement. This change was made to better utilize the available space and more effectively arrange the remaining components. Additionally, at first, all of the plates were spaced equally apart, but later on, we adjusted this because we needed more room between the upper locations to accommodate everything, and we also reduced the space between the final two because that is where we would place all of the electronic components in order to maximize efficiency.

Wheel


Fig 2: CAD Model for Wheel of TWSBR https://github.com/Divyakumar6163/TWSBR/blob/main/CAD%20MODEL/Wheel.SLDPRT

The wheel is 6.5 cm in diameter and 3 cm thick. There will be an extension of about 2.2 cm for placement into the motor shaft. The aforementioned dimensions are displayed in the cad model This wheel fits completely within the tolerance limit and is the most accurate and precise fitment. The diameter of the extension part in the wheel is 3mm.

ESP 32


Fig 3: ESP 32 (MicroController) https://github.com/Divyakumar6163/TWSBR/blob/main/CAD%20MODEL/ESP32.SLDPRT

The ESP32 microcontroller model shown above was created by taking into account just the crucial components of the microcontroller. Located above the plate is the microcontroller.

Battery Casing


Fig 4: CAD of Battery Casing https://github.com/Divyakumar6163/TWSBR/blob/main/CAD%20MODEL/Batter%20Casing.SLDPRT

A Cad model Battery casing, is made to hold four AA batteries (11.1 V each) at once and to keep the batteries separate from one another. Battery separation is essential to prevent the batteries from losing touch with one another. The battery shell is 7.6 cm by 5.4 cm in total. The precise dimensions are 4.4 x 6.6 cm.

Battery


Fig 5: A cell to power the system https://github.com/Divyakumar6163/TWSBR/blob/main/CAD%20MODEL/Battery.SLDPRT

The battery that we are going to use to supply the project with power is represented by the CAD model that can be seen above. Each of the batteries has the capacity to supply 11.1V, and we are utilizing four of them.

Battery & Battery Casing


Fig 6: Assembly of battery and battery casing https://github.com/Divyakumar6163/TWSBR/blob/main/CAD%20MODEL/Battery%20Assembly.SLDASM

This is the assembly of the battery and battery casing which is directly going to connect with the main body i.e. main casing skeleton of the model.

Main Casing


Fig 7: Outer Structure of Robot https://github.com/Divyakumar6163/TWSBR/blob/main/CAD%20MODEL/main%20casing.SLDPRT

This shows the two stages of designing the casing of the robot which serves as the skeleton of the project. The fetal structure on the left throws light on the initial idea of the frame. Eventually, we decided to add an extension to the model so that a bearing can be attached. This bearing would prevent the bending of the shaft and consequently save the motor from damage.

MPU 6050


Fig 8: CAD of gyroscope
https://github.com/Divyakumar6163/TWSBR/blob/main/CAD%20MODEL/MPU%206050.SLDPRT

The above figure shows the CAD model of the gyroscope. The model that we are going to be using for this project is the MPU6050. It is going to give us the motion-related parameters of the robot which is going to be utilized in the equations to stabilize the robot and balance it well.

Motor


Fig 9: Motor and clip to hold motor on the body of robot. https://github.com/Divyakumar6163/TWSBR/blob/main/CAD%20MODEL/motor.SLDPRT

This is the motor the robot is going to control the movement. Initially, there were no bearings then we added them as it is the most important part of the robot to avoid the motor from being destroyed.

## COST ANALYSIS

Component | Cost
Micro-controller | ₹ 500 - ₹ 2000
Motors | ₹ 200 - ₹ 800
Motor Drivers | ₹ 100 - ₹ 150
Battery | ₹ 200 - ₹ 300
Accelerometer & Gyroscope sensor | ₹ 200 - ₹ 600
Plates/Casing & Rods | ₹ 500 - ₹ 700
Wheels | ₹ 50 - ₹ 100
3D Printing Filament | ₹ 700 - ₹ 900

The overall Estimated cost to make such a project is ₹ 2450 - ₹ 5550 at the “Proof of Concept” stage.

## APPLICATIONS

Our project constitutes a two-wheeled self-balancing robot which is accommodated in a design that consists of three plates and largely focuses on domestic utility. The bottom two plates serve the purpose of providing space for all the electronic components and the topmost plate is going to be utilized for transportation purposes. This versatile model also holds the potential to cater to industries with customizable modifications to suit the nature of the application. The design and compact nature of this robot make it an easy alternative for personal transportation of goods and surveillance. This project is thus a step towards redefining the industrial landscape and presents our take on how a robot with such a vast potential can be designed.
Being actively stabilised means that the robot can correct for any disturbances which may otherwise cause a statically stable robot to tip over, even with a higher centre of mass. Two-wheeled robots can be taller, with a small footprint, making them quite suitable for indoor environments, because they can fit through narrow corridors and tight corners. Because two-wheeled robots can lean fore and aft to re-stabilize themselves, they are also able to maintain stability on inclines, by leaning into the slope.

## FUTURE SCOPE OF DEVELOPMENT

From the point of view of future development, the following areas hold tremendous scope:

### 1. Sensors: Using sensory devices such as an ultrasonic sensor that intimates the

robot regarding the surroundings in which it is operating can be procured and put to use to identify obstacles.

2.Navigation: Surveying its surroundings is a feature that would boost the utility of a self balancing robot beyond the current scope. This can be realized by a combination of machine learning into the system. This could be a massive step towards complete autonomous navigation.

### 3. Payload Capacity: The maximum weight that such robots can carry is often a

limiting condition. More the limit is pushed, the more the range of operation of that particular robot expands.

### 4. Energy Efficiency: Efficient consumption of energy in today's world is of prime

importance considering the scarce nature of resources. Thus using powering devices (batteries) and powered devices (motors), of better ratings and efficiency is essential in order to improve the performance of the robot

### 5. Mechanical Design: Calculations often have a large scope for precision along with

some mechanical considerations. The incorporation of these along with experience into the model can act as a catalyst to magnify the efficiency of a TWSBR.

## TIMELINE

*We postponed every step in the timeline by 40 days due to the ideation deadline extension.

Here is the brief structure of our Timeline and we will stick to it.

### 1. July 2024: Gearing Up

- July 1 - July 15: Procurement Phase
Allocate 1.5 weeks for researching, sourcing, and purchasing necessary components and materials.
- July 16 - July 22: Assembly Phase
Allocate 1 week for the assembly of the bot, ensuring all components are correctly integrated.

### 2. Coding and Programming Phase

- July 16 - Augest 6: Concurrent Coding
- Begin coding simultaneously with assembly to maximize efficiency.
- Develop the software architecture for the self-balancing mechanism.

### 3. PID Control Implementation

- August 7 - Augest 13: PID Tuning and Integration
-Dedicate a week to implement and fine-tune the Proportional Integral Derivative (PID) control algorithm.
-Test and adjust parameters to achieve optimal balance and stability.

### 4. Testing and Iteration

- Augest 14 - Augest 27: Intensive Testing
- Conduct rigorous testing to evaluate the bot's performance under various conditions.
- Identify limitations and areas for improvement through iterative testing.

### 5. Documentation and Finalization

- Augest 28 - Augest 31: Documentation and Submission
-Compile documentation detailing the design, development process, and testing results.
- Ready with the “Proof of Concept” for submission to ROBOFEST4.0. **All the dates mentioned above are tentative and subject to change per the guidelines provided.

## DIMENSIONS

Size of Robot Proposed for Proof of Concept

- Length in cm: 15cm
- Width in cm: 10cm
- Height in cm: 20cm

The size of the Robot proposed as a prototype

- Length in cm: 45cm
- Width in cm: 30cm
- Height in cm: 60cm

## ABOUT THE TEAM

Mentor:

Dr. Satyanarayan Panigrahi
Associate Professor
School of Mechanical Sciences

Ph.D. Mechanical (Technical Acoustics) - 2007 Indian Institute of Science, Bangalore

Research Interests

Technical Acoustics, Industrial Noise Control, Automotive noise control, Acoustic based Condition Monitoring of Machines, and Musical Acoustics.

Team Members:

1. Ayush Gupta
2. Divya Kumar
3. Jiya Chakraborty
4. Rachit Jain
5. Vivek Singh

## REFERENCES

- [1] C. Iwendi, M. A. Alqarni, J. H. Anajemba, A. S. Alfakeeh, Z. Zhang and A. K. Bashir, "Robust Navigational Control of a Two-Wheeled Self-Balancing Robot in a Sensed Environment," in IEEE Access, vol. 7, pp. 82337-82348, 2019, doi: 10.1109/ACCESS.2019.2923916.
keywords: | {Mobile | robots;Robot | sensing | systems;Mathematical
model;Wheels;Robot | kinematics;Kalman | filters;TWSBR;32-bit
Microcontroller;robust control;PD-PI;sensed environment;IoT},
- Ronald Ping Man Chan, Karl A. Stol, C. Roger Halkyard,
Review of modelling and control of two-wheeled robots,
Annual Reviews in Control,
Volume 37, Issue 1,

GITHUB LINK: https://github.com/Divyakumar6163/TWSBR

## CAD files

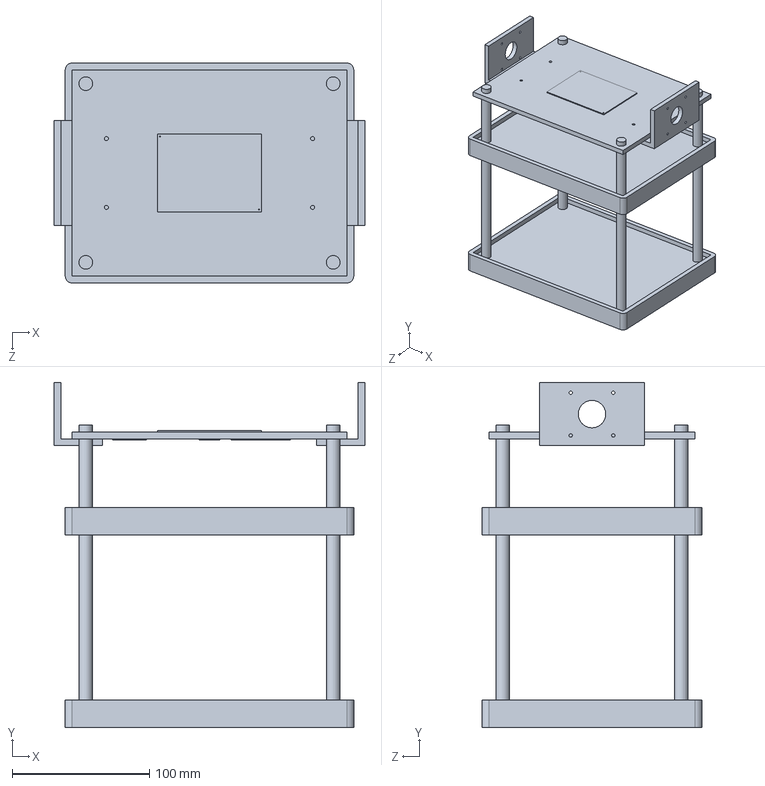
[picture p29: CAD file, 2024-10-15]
CAD/CAD MODEL Update/main casing.SLDPRT
226.0 x 251.0 x 160.0 mm

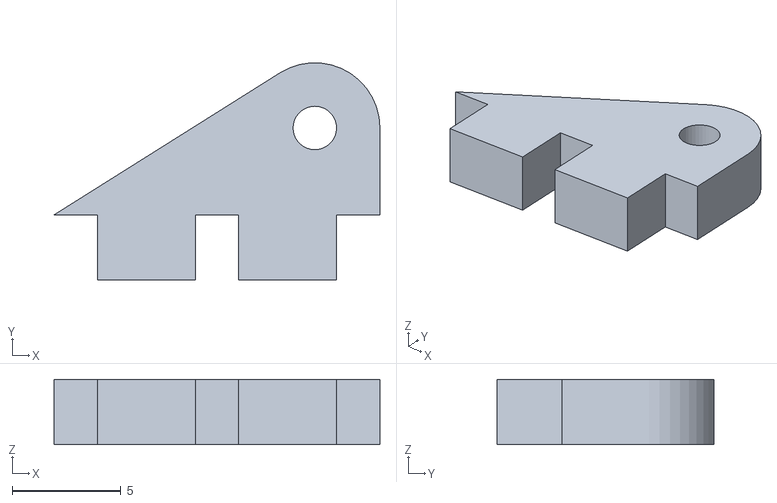
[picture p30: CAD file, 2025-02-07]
CAD/Aluminium Model/Camera/Hinge Assembly - Hinge-1.STL
15.0 x 9.99 x 3.00

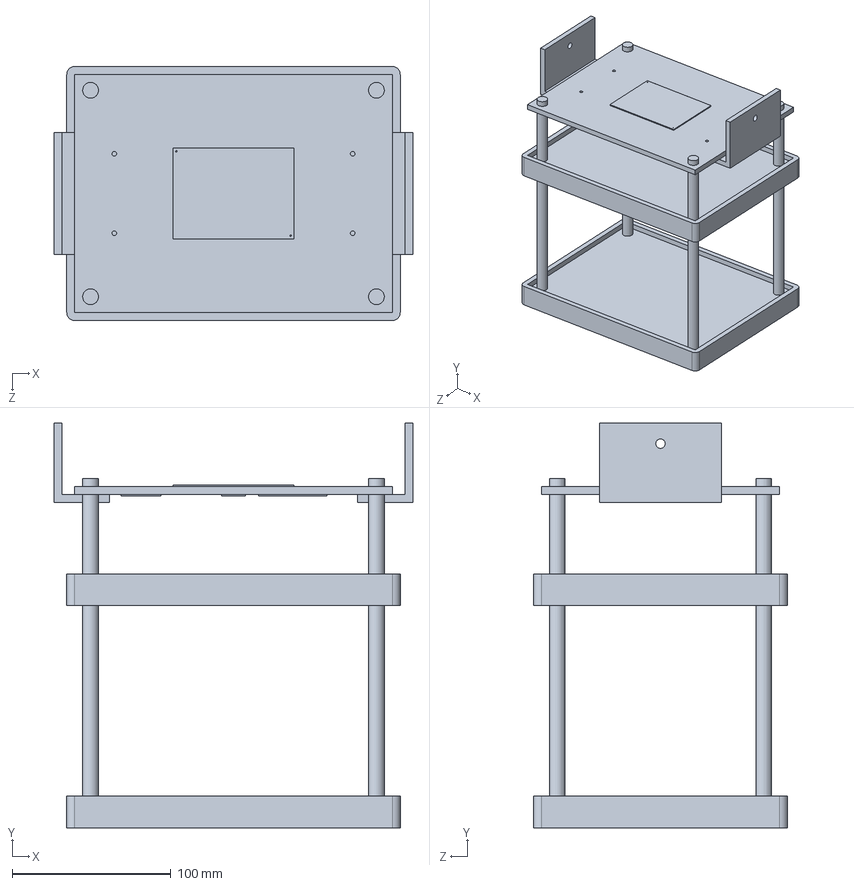
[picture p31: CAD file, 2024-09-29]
CAD/CAD MODEL/main casing.SLDPRT
226.0 x 255.0 x 160.0 mm

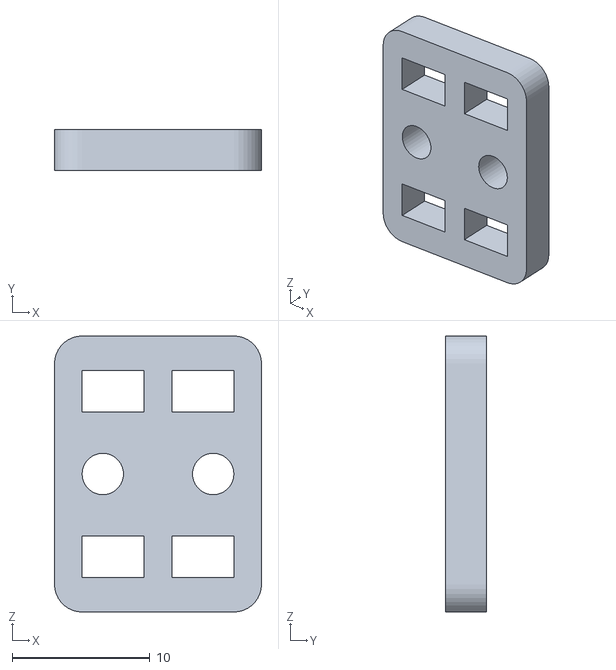
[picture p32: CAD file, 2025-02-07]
CAD/Aluminium Model/Camera/Hinge Assembly - Hinge_Base-1.STL
15.0 x 3.00 x 20.0

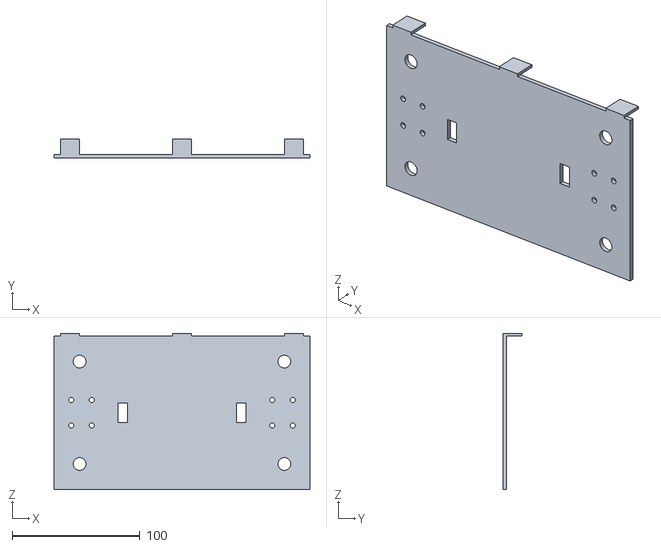
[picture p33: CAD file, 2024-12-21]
CAD/Aluminium Model/Low Plate Assembly - Low Plate-1.STL
200.0 x 15.0 x 122.0

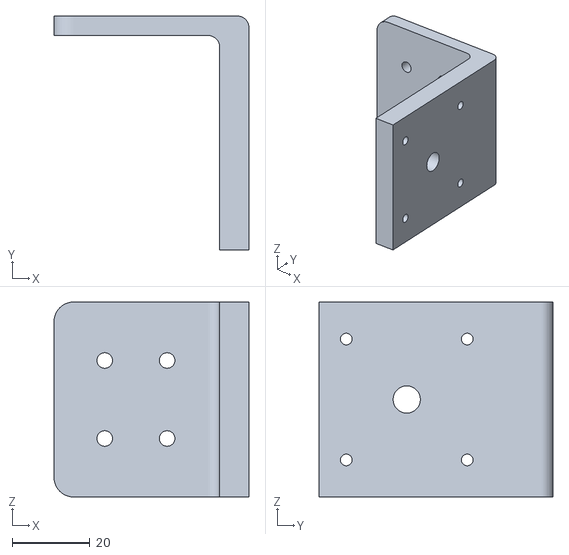
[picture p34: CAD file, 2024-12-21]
CAD/Aluminium Model/Low Plate Assembly - Flang-7.STL
50.0 x 60.0 x 50.0

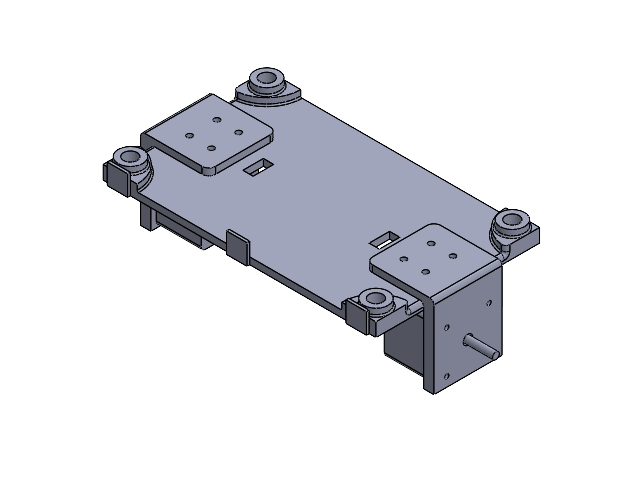
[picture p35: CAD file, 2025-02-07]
CAD/3D Print New/Low Plate Assembly.SLDASM
Low Plate
Flang x 2
stepper_motor x 2

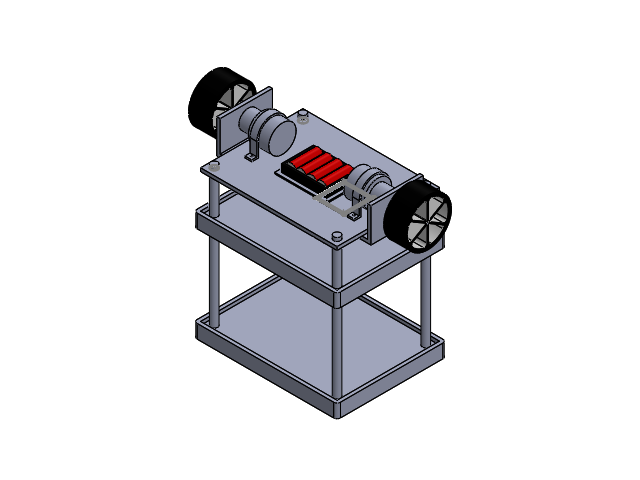
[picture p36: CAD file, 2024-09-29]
CAD/CAD MODEL/TWSBR.SLDASM
main casing
motor x 2
Wheel x 2
Batter Casing
Battery x 4
L298N Motor Driver
MPU 6050
ESP32

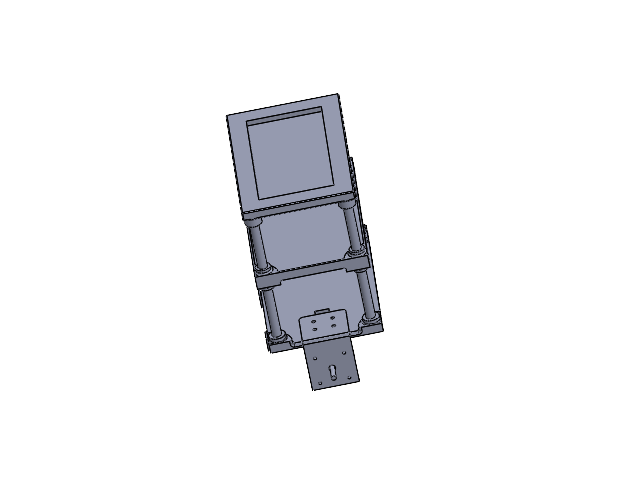
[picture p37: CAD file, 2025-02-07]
CAD/3D Print New/TWSBR Final.SLDASM
Mid Plate
Top Plate
Rod x 8
Low Plate
Flang x 2
stepper_motor x 2

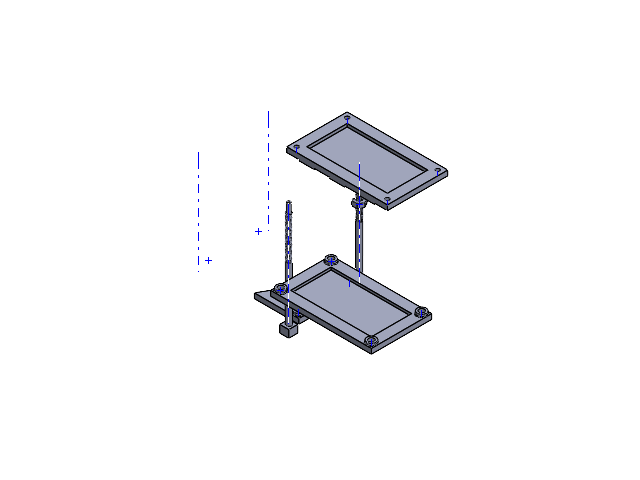
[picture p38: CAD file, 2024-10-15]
CAD/3D_Print/Casing Assemby.SLDASM
Low-Mid Plate x 2
Top Plate
Final Rod x 4
Nut

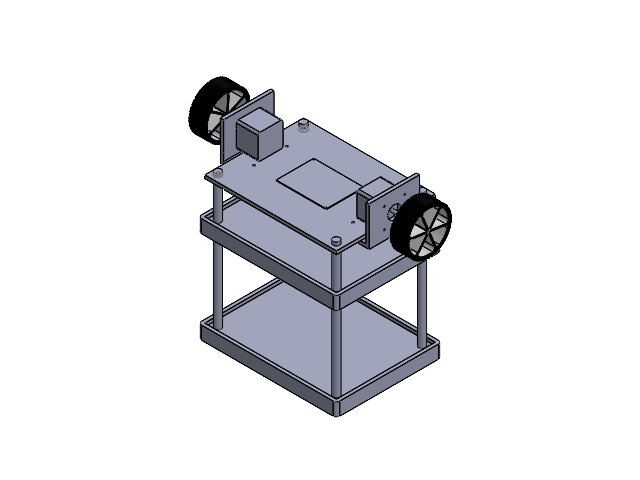
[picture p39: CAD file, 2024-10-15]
CAD/CAD MODEL Update/TWSBR.SLDASM
main casing
Wheel x 2
MPU 6050
ESP32
stepper_motor x 2

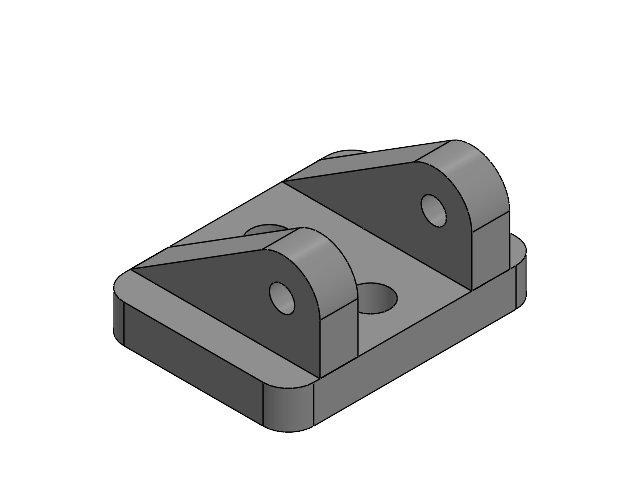
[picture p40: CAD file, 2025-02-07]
CAD/Aluminium Model/Camera/Hinge Assembly.SLDASM
Hinge_Base
Hinge x 2

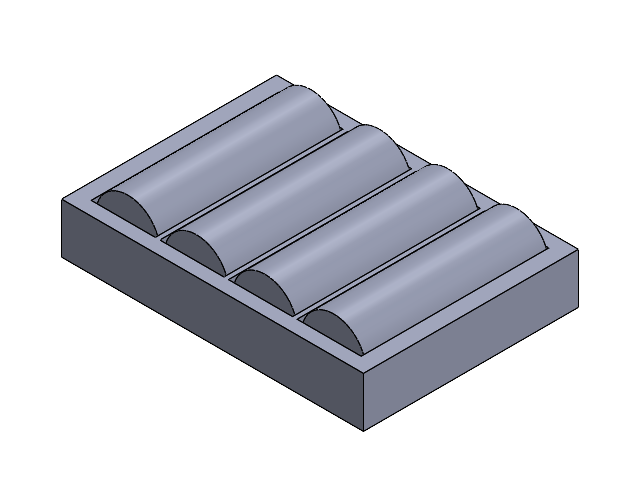
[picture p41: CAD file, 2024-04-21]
CAD/CAD MODEL/Battery Assembly.SLDASM
Batter Casing
Battery x 4

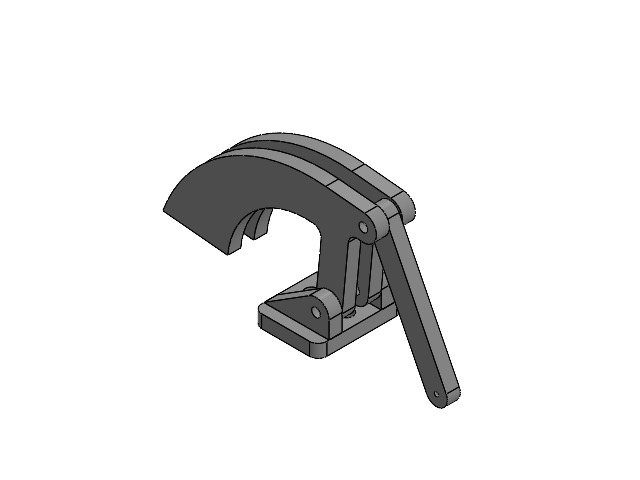
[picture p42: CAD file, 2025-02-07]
CAD/Aluminium Model/Camera/Assem3.SLDASM
Hinge_Base
Hinge x 2
horn x 2
push_rod

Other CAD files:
CAD/Aluminium Model/Camera/Hinge Assembly - Hinge-2.STL
CAD/3D Print New/Beaker Assembly.SLDASM
CAD/Aluminium Model/Low Plate Assembly - Flang-6.STL
CAD/3D Print New/Battery.SLDPRT
CAD/3D Print New/Beaker Assembly.x_t
CAD/3D Print New/Beaker Base - Copy.SLDPRT
CAD/3D Print New/Beaker Base.SLDPRT
CAD/3D Print New/Beaker Base.STL
CAD/3D Print New/Big Seprator - Copy.SLDPRT
CAD/3D Print New/Big Seprator.SLDPRT
CAD/3D Print New/Big Seprator.STL
CAD/3D Print New/Flang.SLDPRT
CAD/3D Print New/Flang.STL
CAD/3D Print New/Low Plate.SLDPRT
CAD/3D Print New/Low Plate.STL
CAD/3D Print New/Mid Plate.SLDPRT
CAD/3D Print New/Mid Plate.STL
CAD/3D Print New/Rod - Copy.SLDPRT
CAD/3D Print New/Rod - Copy.STL
CAD/3D Print New/Rod.SLDPRT
CAD/3D Print New/Rod.STL
CAD/3D Print New/Small Seprator - Copy.SLDPRT
CAD/3D Print New/Small Seprator.SLDPRT
CAD/3D Print New/Small Seprator.STL
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

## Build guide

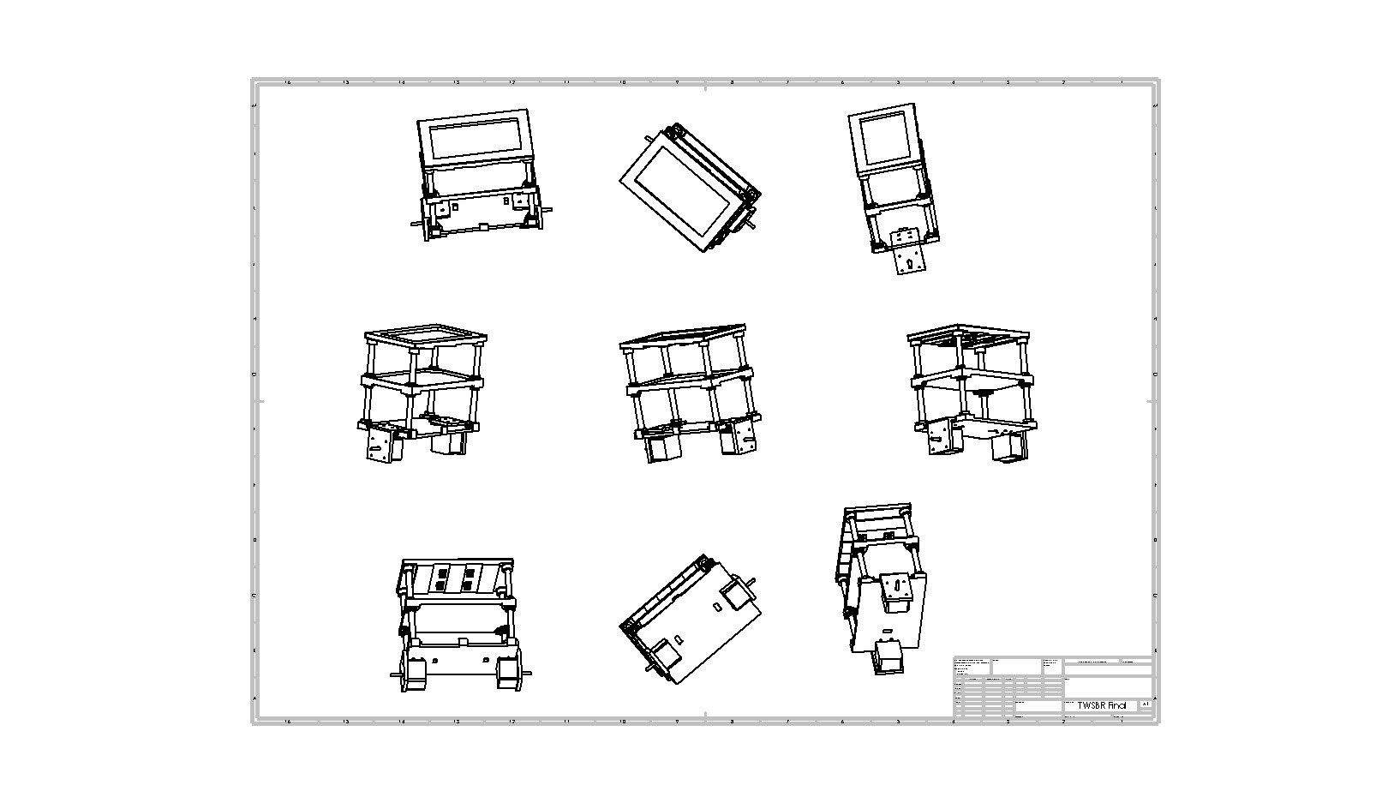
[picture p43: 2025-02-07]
CAD/3D Print New/TWSBR Final.JPG

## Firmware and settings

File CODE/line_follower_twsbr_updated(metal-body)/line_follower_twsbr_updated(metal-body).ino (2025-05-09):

#include <Wire.h>                                          

int gyro_address = 0x68;                                   
int acc_calibration_value = -660;                        

//Various settings
float pid_p_gain = 13;    //13                                  
float pid_i_gain = 0.55; //1                                     
float pid_d_gain = 5;  //3.6                                     
float turning_speed = 10;                                    
float turning_speed_slow = 5;                               
float max_target_speed = 4;                                

byte start, received_byte=0, low_bat;

int left_motor, throttle_left_motor, throttle_counter_left_motor, throttle_left_motor_memory;
int right_motor, throttle_right_motor, throttle_counter_right_motor, throttle_right_motor_memory;
int battery_voltage;
int receive_counter;
int gyro_pitch_data_raw, gyro_yaw_data_raw, accelerometer_data_raw;

long ir_timer_start;

long gyro_yaw_calibration_value, gyro_pitch_calibration_value;

unsigned long loop_timer;

float angle_gyro,angle_gyro_yaw=0, angle_acc=0, angle, self_balance_pid_setpoint;
float pid_error_temp, pid_i_mem, pid_setpoint, gyro_input, pid_output, pid_last_d_error;
float pid_output_left, pid_output_right;

// const int irPin1=10;
// const int irPin2=11;
// const int irPin3=12;

// const int irPin4=2;
// const int irPin5=3;

// const int irPin6=4; //right 90
// const int irPin7=9; //left 90

const int irPin1=2;//left 90
const int irPin2=3;
const int irPin3=4;

const int irPin4=9;
const int irPin5=10;

const int irPin6=11; 
const int irPin7=12; //right 90

void setup(){
  Serial.begin(9600);                                                       //Start the serial port at 9600 kbps
  Wire.begin();                                                             //Start the I2C bus as master
  TWBR = 12;                                                                //Set the I2C clock speed to 400kHz

  //To create a variable pulse for controlling the stepper motors a timer is created that will execute a piece of code (subroutine) every 20us
  //This subroutine is called TIMER2_COMPA_vect
  TCCR2A = 0;                                                               //Make sure that the TCCR2A register is set to zero
  TCCR2B = 0;                                                               //Make sure that the TCCR2A register is set to zero
  TIMSK2 |= (1 << OCIE2A);                                                  //Set the interupt enable bit OCIE2A in the TIMSK2 register
  TCCR2B |= (1 << CS21);                                                    //Set the CS21 bit in the TCCRB register to set the prescaler to 8
  OCR2A = 39;                                                               //The compare register is set to 39 => 20us / (1s / (16.000.000MHz / 8)) - 1
  TCCR2A |= (1 << WGM21);                                                   //Set counter 2 to CTC (clear timer on compare) mode


  // 1sec timer 1 
  // Configure Timer1 for CTC mode
  TCCR1A = 0;                 // Clear Timer/Counter Control Register A
  TCCR1B = 0;                 // Clear Timer/Counter Control Register B
  TCCR1B |= (1 << WGM12);     // Set WGM12 bit for CTC mode
  
  TCCR1B |= (1 << CS12) | (1 << CS10); // Set prescaler to 1024 
  // Set compare match value for 1 second
  OCR1A = 15624;              // 1-second interval with 16 MHz clock and 1024 prescaler
  // OCR1A = 7812;  //0.5 sec timer
  // OCR1A = 6250;   //0.4sec timer
  TIMSK1 |= (1 << OCIE1A);    // Enable Timer1 Compare Match A interrupt
  // sei();    // Enable global interrupts

  
  //By default the MPU-6050 sleeps. So we have to wake it up.
  Wire.beginTransmission(gyro_address);                                     //Start communication with the address found during search.
  Wire.write(0x6B);                                                         //We want to write to the PWR_MGMT_1 register (6B hex)
  Wire.write(0x00);                                                         //Set the register bits as 00000000 to activate the gyro
  Wire.endTransmission();                                                   //End the transmission with the gyro.
  //Set the full scale of the gyro to +/- 250 degrees per second
  Wire.beginTransmission(gyro_address);                                     //Start communication with the address found during search.
  Wire.write(0x1B);                                                         //We want to write to the GYRO_CONFIG register (1B hex)
  Wire.write(0x00);                                                         //Set the register bits as 00000000 (250dps full scale)
  Wire.endTransmission();                                                   //End the transmission with the gyro
  //Set the full scale of the accelerometer to +/- 4g.
  Wire.beginTransmission(gyro_address);                                     //Start communication with the address found during search.
  Wire.write(0x1C);                                                         //We want to write to the ACCEL_CONFIG register (1A hex)
  Wire.write(0x08);                                                         //Set the register bits as 00001000 (+/- 4g full scale range)
  Wire.endTransmission();                                                   //End the transmission with the gyro
  //Set some filtering to improve the raw data.
  Wire.beginTransmission(gyro_address);                                     //Start communication with the address found during search
  Wire.write(0x1A);                                                         //We want to write to the CONFIG register (1A hex)
  Wire.write(0x03);                                                         //Set the register bits as 00000011 (Set Digital Low Pass Filter to ~43Hz)
  Wire.endTransmission();                                                   //End the transmission with the gyro 

  pinMode(13, OUTPUT);                                                      //Configure digital poort 6 as output
  
  pinMode(5, OUTPUT);                                                       //Configure digital poort 2 as output
  pinMode(6, OUTPUT);                                                       //Configure digital poort 3 as output
  pinMode(7, OUTPUT);                                                       //Configure digital poort 4 as output
  pinMode(8, OUTPUT); 

  
  pinMode(irPin1, INPUT);                                                   
  pinMode(irPin2, INPUT);                                                   
  pinMode(irPin3, INPUT);       
  pinMode(irPin4, INPUT);       
  pinMode(irPin5, INPUT); 
  pinMode(irPin6, INPUT); 
  pinMode(irPin7, INPUT);        
  
  for(receive_counter = 0; receive_counter < 500; receive_counter++){       //Create 500 loops
    if(receive_counter % 15 == 0)digitalWrite(13, !digitalRead(13));        //Change the state of the LED every 15 loops to make the LED blink fast
    Wire.beginTransmission(gyro_address);                                   //Start communication with the gyro
    Wire.write(0x43);                                                       //Start reading the Who_am_I register 75h
    Wire.endTransmission();                                                 //End the transmission
    Wire.requestFrom(gyro_address, 4);                                      //Request 2 bytes from the gyro
    gyro_yaw_calibration_value += Wire.read()<<8|Wire.read();               //Combine the two bytes to make one integer
    gyro_pitch_calibration_value += Wire.read()<<8|Wire.read();             //Combine the two bytes to make one integer
    delayMicroseconds(3700);                                                //Wait for 3700 microseconds to simulate the main program loop time
  }
  gyro_pitch_calibration_value /= 500;                                      //Divide the total value by 500 to get the avarage gyro offset
  gyro_yaw_calibration_value /= 500;                                        //Divide the total value by 500 to get the avarage gyro offset

  loop_timer = micros() + 4000;                                             //Set the loop_timer variable at the next end loop time

}

int counter=0;
int time_counter=0;

int timetorun=750;
int turning=0;
long turningOffset=0;
long turningFinal=0;

int flagIR=0;
bool started=false;
bool noIRdet=false;
int cntNoIRdetTime=0;

int timeFirstDetected=0;
int leftdetected = 0, rightdetected = 0;
int leftdetectedAgain = 0, rightdetectedAgain = 0;

void loop(){
  counter++; // 4ms
  time_counter++;

  if(time_counter>=timetorun){
    time_counter=0;
  }
  // if(Serial.available()){                                                   //If there is serial data available
  //   received_byte = Serial.read();                                          //Load the received serial data in the received_byte variable
  //   receive_counter = 0;                                                    //Reset the receive_counter variable
  // }

    // int IRL = digitalRead(irPin1) | digitalRead(irPin4);
    // int IRS = digitalRead(irPin2);
    // int IRR = digitalRead(irPin3) |digitalRead(irPin5);

    
    // int IRLeft = digitalRead(irPin7);
    // int IRRight = digitalRead(irPin6);

    int IRL = digitalRead(irPin5) | digitalRead(irPin6);
    int IRS = digitalRead(irPin4);
    int IRR = digitalRead(irPin2) |digitalRead(irPin3);

    
    int IRLeft = digitalRead(irPin7);
    int IRRight = digitalRead(irPin1);

    // IRL=0;
    // IRS=0;
    // IRR=0;
    IRLeft=0;
    IRRight=0;

    // Serial.println(IRL);
    // Serial.println(IRS);
    // Serial.println(IRR);
    // Serial.println(IRLeft);
    // Serial.println(IRRight);
    // Serial.println(angle_gyro_yaw);
    
    // Serial.println(received_byte);
    // Serial.print("Left IR ");
    // Serial.println(IRLeft);
    // Serial.print("leftdetected ");
    // Serial.println(leftdetected);
    // Serial.print("leftdetectedAgain ");
    // Serial.println(leftdetectedAgain);
   
   
    if(leftdetected && IRLeft && leftdetectedAgain==0 && timeFirstDetected>1){
      leftdetectedAgain=1;
      leftdetected=0;
      turning=1;
      turningOffset=angle_gyro_yaw;
      turningFinal=turningOffset-90;
      // Serial.print("Left 90");
      
    }else if(rightdetected && IRRight && rightdetectedAgain==0 && timeFirstDetected>1){
      rightdetectedAgain=1;
      rightdetected=0;
      turning=1;
      turningOffset=angle_gyro_yaw;
      turningFinal=turningOffset+90;
      // Serial.print("Right 90");
    }

      //  Serial.print("turning ");
      //  Serial.println(turning);

      //  Serial.print("IRLeft ");
      //  Serial.println(IRLeft);

    if(turning==0 && IRLeft){
      leftdetected=1;
      timeFirstDetected=1;
    }else if(turning==0 && IRRight){
      rightdetected=1;
      timeFirstDetected=1;
    }

    if(!IRL && !IRS && !IRR && !IRLeft && !IRRight && turning==0 && started){
      if(!noIRdet)
      {
        noIRdet=true;
        cntNoIRdetTime=0;
      }
    }else{
      noIRdet=false;
      cntNoIRdetTime=0;
    }

 
  if(counter>=30){
    if(turning==0)
    {
      // Serial.println("turn=0");

      // if(IRLeft){
      //   turning=1;
      //   turningOffset=angle_gyro_yaw; 
      //   turningFinal=turningOffset-90;
      // }else if(IRRight){
      //   turning=1;
      //   turningOffset=angle_gyro_yaw;
      //   turningFinal=turningOffset+90;
      // }
      if(noIRdet && cntNoIRdetTime>=4){
      // if((cntNoIRdetTime%4)>=2){
        if(received_byte==0){
          received_byte = 0x08;
          receive_counter=5;
          counter=0;
        }
      // }
      }
      else if(leftdetected || rightdetected){
        if(received_byte==0){
          received_byte=0x08;
          receive_counter=5;
          counter=0;
        }
      }
      else if(IRS && received_byte==0){
        started=true;
        received_byte = 0x04;
        receive_counter=5;
        counter=0;
      }
      else if(IRL){
        received_byte = 0x01;
        receive_counter=0;
        counter=0;
        // turning=1;
        // turningOffset=angle_gyro_yaw; 
        // turningFinal=turningOffset-5;
      }else if(IRR){
        received_byte = 0x02;
        receive_counter=0;
        counter=0;
        // turning=1;
        // turningOffset=angle_gyro_yaw; 
        // turningFinal=turningOffset+5;
      }
    }
    else if(abs(turningOffset-turningFinal)>=5){
      turningOffset=angle_gyro_yaw;
      // Serial.println("hii ");
      // Serial.print(turningOffset);
      // Serial.print(" ");
      // Serial.println(turningFinal);
      if(turningOffset>turningFinal){
        received_byte = 0x01;
        receive_counter=0;
        // counter=0;
        // Serial.println("Left");
      }else{
        received_byte = 0x02;
        receive_counter=0;
        // counter=0;
        // Serial.println("Right");
      }
    }else{
      turning=0;
      leftdetectedAgain=0;
      rightdetectedAgain=0;
      timeFirstDetected=0;
      // Serial.println("Dhokebaaz");
      // Serial.print(turningOffset);
      // Serial.print(" ");
      // Serial.println(turningFinal);
    }
    // counter=0;
  }

//  Serial.print("Angle Gyro yaw");
//  Serial.println(angle_gyro_yaw);

  if(receive_counter <= 25)receive_counter ++;                              
  //The received byte will be valid for 25 program loops (100 milliseconds)
  else received_byte = 0x00;                                                //After 100 milliseconds the received byte is deleted
  
  Wire.beginTransmission(gyro_address);                                     //Start communication with the gyro
  Wire.write(0x3F);                                                         //Start reading at register 3F
  Wire.endTransmission();                                                   //End the transmission
  Wire.requestFrom(gyro_address, 2);                                        //Request 2 bytes from the gyro
  accelerometer_data_raw = Wire.read()<<8|Wire.read();                      //Combine the two bytes to make one integer
  accelerometer_data_raw += acc_calibration_value;                          //Add the accelerometer calibration value
  if(accelerometer_data_raw > 8200)accelerometer_data_raw = 8200;           //Prevent division by zero by limiting the acc data to +/-8200;
  if(accelerometer_data_raw < -8200)accelerometer_data_raw = -8200;         //Prevent division by zero by limiting the acc data to +/-8200;

  angle_acc = asin((float)accelerometer_data_raw/8200.0)* 57.296;           //Calculate the current angle according to the accelerometer

  if(start == 0 && angle_acc > -0.5&& angle_acc < 0.5){                     //If the accelerometer angle is almost 0
  // if(start == 0){
    angle_gyro = angle_acc;                                                 //Load the accelerometer angle in the angle_gyro variable
    angle_gyro_yaw = angle_acc;
    start = 1;                                                              //Set the start variable to start the PID controller
  }
  
  Wire.beginTransmission(gyro_address);                                     //Start communication with the gyro
  Wire.write(0x43);                                                         //Start reading at register 43
  Wire.endTransmission();                                                   //End the transmission
  Wire.requestFrom(gyro_address, 4);                                        //Request 4 bytes from the gyro
  gyro_yaw_data_raw = Wire.read()<<8|Wire.read();                           //Combine the two bytes to make one integer
  gyro_pitch_data_raw = Wire.read()<<8|Wire.read();                         //Combine the two bytes to make one integer
  
  gyro_pitch_data_raw -= gyro_pitch_calibration_value;                      //Add the gyro calibration value
  angle_gyro += gyro_pitch_data_raw * 0.000031;                             //Calculate the traveled during this loop angle and add this to the angle_gyro variable
  
  gyro_yaw_data_raw -= gyro_yaw_calibration_value;                          //Add the gyro calibration value
  angle_gyro_yaw+=gyro_yaw_data_raw * 0.000031;  
  //Uncomment the following line to make the compensation active
  angle_gyro -= gyro_yaw_data_raw * 0.0000003;                            //Compensate the gyro offset when the robot is rotating

  angle_gyro = angle_gyro * 0.9996 + angle_acc * 0.0004;                    //Correct the drift of the gyro angle with the accelerometer angle
  // angle_gyro_yaw = angle_gyro_yaw*0.9996 + angle_acc * 0.0004;

  pid_error_temp = angle_gyro - self_balance_pid_setpoint - pid_setpoint;
  if(pid_output > 10 || pid_output < -10)pid_error_temp += pid_output * 0.015 ;

  pid_i_mem += pid_i_gain * pid_error_temp;                                 //Calculate the I-controller value and add it to the pid_i_mem variable
  if(pid_i_mem > 400)pid_i_mem = 400;                                       //Limit the I-controller to the maximum controller output
  else if(pid_i_mem < -400)pid_i_mem = -400;
  //Calculate the PID output value
  pid_output = pid_p_gain * pid_error_temp + pid_i_mem + pid_d_gain * (pid_error_temp - pid_last_d_error);
  if(pid_output > 400)pid_output = 400;                                     //Limit the PI-controller to the maximum controller output
  else if(pid_output < -400)pid_output = -400;

  pid_last_d_error = pid_error_temp;                                        //Store the error for the next loop

  if(pid_output < 5 && pid_output > -5)pid_output = 0;                      //Create a dead-band to stop the motors when the robot is balanced

  // if(angle_gyro > 60 || angle_gyro < -60 || start == 0 || low_bat == 1){    //If the robot tips over or the start variable is zero or the battery is empty
  //   pid_output = 0;                                                         //Set the PID controller output to 0 so the motors stop moving
  //   pid_i_mem = 0;                                                          //Reset the I-controller memory
  //   start = 0;                                                              //Set the start variable to 0
  //   self_balance_pid_setpoint = 0;                                          //Reset the self_balance_pid_setpoint variable
  //   Serial.println("Stopping..........");
  // }

  pid_output_left = pid_output;                                             //Copy the controller output to the pid_output_left variable for the left motor
  pid_output_right = pid_output;                                            //Copy the controller output to the pid_output_right variable for the right motor

  if(received_byte & B00000001){                                            //If the first bit of the receive byte is set change the left and right variable to turn the robot to the left
    pid_output_left += turning_speed;                                       //Increase the left motor speed
    pid_output_right -= turning_speed;                                      //Decrease the right motor speed
  }
  if(received_byte & B00000010){                                            //If the second bit of the receive byte is set change the left and right variable to turn the robot to the right
    pid_output_left -= turning_speed;                                       //Decrease the left motor speed
    pid_output_right += turning_speed;                                      //Increase the right motor speed
  }

  if(received_byte & B00010000){                                            //If the first bit of the receive byte is set change the left and right variable to turn the robot to the left
    pid_output_left += turning_speed_slow;                                       //Increase the left motor speed
    pid_output_right -= turning_speed_slow;                                      //Decrease the right motor speed
  }
  if(received_byte & B00100000){                                            //If the second bit of the receive byte is set change the left and right variable to turn the robot to the right
    pid_output_left -= turning_speed_slow;                                       //Decrease the left motor speed
    pid_output_right += turning_speed_slow;                                      //Increase the right motor speed
  }

  if(received_byte & B00000100){                                            //If the third bit of the receive byte is set change the left and right variable to turn the robot to the right
    if(pid_setpoint > -2.5)pid_setpoint -= 0.04;                            //Slowly change the setpoint angle so the robot starts leaning forewards
    if(pid_output > max_target_speed * -1)pid_setpoint -= 0.005;            //Slowly change the setpoint angle so the robot starts leaning forewards
  }
  if(received_byte & B00001000){                                            //If the forth bit of the receive byte is set change the left and right variable to turn the robot to the right
    if(pid_setpoint < 2.5)pid_setpoint += 0.04;                             //Slowly change the setpoint angle so the robot starts leaning backwards
    if(pid_output < max_target_speed)pid_setpoint += 0.005;                 //Slowly change the setpoint angle so the robot starts leaning backwards
  }
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

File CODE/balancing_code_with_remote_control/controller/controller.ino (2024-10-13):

#include <WiFi.h>
#include <WebServer.h>

// Replace with your own credentials
const char *ssid = "ESP32-Car-Control";
const char *password = "12345678";  // Password for the hotspot

// Initialize web server on port 80
WebServer server(80);

// Movement control variables
String carDirection = "STOP";

// Define motor control pins (replace with actual pins)
const int motorPin1 = 5;  // Motor A
const int motorPin2 = 18; // Motor A


// Function to handle the control
void handleControl() {
  if (server.hasArg("direction")) {
    carDirection = server.arg("direction");

    // Control the motors based on direction
    controlCar();

    // Send response (can be ignored by the client)
    server.send(200, "text/plain", "OK");
  }
}

// Function to control car movement
void controlCar() {
  if (carDirection == "FORWARD") {
    // Set motors to move forward
    digitalWrite(motorPin1, HIGH);
    digitalWrite(motorPin2, 1);

  } else if (carDirection == "BACKWARD") {
    // Set motors to move backward
    digitalWrite(motorPin1, LOW);
    digitalWrite(motorPin2, 0);

  } else if (carDirection == "LEFT") {
    // Set motors to rotate left
    digitalWrite(motorPin1, LOW);
    digitalWrite(motorPin2, HIGH);

  } else if (carDirection == "RIGHT") {
    // Set motors to rotate right
    digitalWrite(motorPin1, HIGH);
    digitalWrite(motorPin2, LOW);

  } else if (carDirection == "STOP") {
    // Stop the motors
    digitalWrite(motorPin1, LOW);
    digitalWrite(motorPin2, LOW);
    Serial.println("Stopping");
  }
}

// Function to handle root path "/"
void handleRoot() {
  String html = "<html><body><h1>ESP32 Car Control</h1>";
  html += "<button onclick=\"sendData('FORWARD')\">Forward</button><br><br>";
  html += "<button onclick=\"sendData('BACKWARD')\">Backward</button><br><br>";
  html += "<button onclick=\"sendData('LEFT')\">Rotate Left</button><br><br>";
  html += "<button onclick=\"sendData('RIGHT')\">Rotate Right</button><br><br>";
  html += "<button onclick=\"sendData('STOP')\">Stop</button><br><br>";
  html += "<script>";
  html += "function sendData(direction) {";
  html += "var xhttp = new XMLHttpRequest();";
  html += "xhttp.open('POST', '/control?direction=' + direction, true);";
  html += "xhttp.send();";
  html += "}";
  html += "</script></body></html>";

  server.send(200, "text/html", html);
}

void setup() {
  // Start Serial Monitor
  Serial.begin(115200);
  
  // Set motor pins as output
  pinMode(motorPin1, OUTPUT);
  pinMode(motorPin2, OUTPUT);


  // Set ESP32 as Access Point
  WiFi.softAP(ssid, password);
  Serial.println("Access Point started");

  // Print IP address
  IPAddress IP = WiFi.softAPIP();
  Serial.print("AP IP address: ");
  Serial.println(IP);

  // Define routes
  server.on("/", handleRoot);
  server.on("/control", handleControl);

  // Start server
  server.begin();
  Serial.println("Server started");
}

void loop() {
  // Handle incoming client requests
  server.handleClient();
}

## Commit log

2024-04-21 Model Completed
    [Arduino Uno.SLDPRT, Batter Casing.SLDPRT, Battery Assembly.SLDASM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]
2024-04-21 bearing added
    [TWSBR.SLDASM, main casing.SLDPRT, motor.SLDPRT]
2024-04-28 updated file structure
    [Arduino Uno.SLDPRT, Batter Casing.SLDPRT, Battery Assembly.SLDASM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]
2024-06-25 ESP 32 Added
    [Arduino Uno.SLDPRT, ESP32.SLDPRT, TWSBR.SLDASM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]
2024-06-30 Report updated
    [TWSBR.SLDASM, main casing.SLDPRT]
2024-09-25 Update in pid code
2024-09-29 CAD Update
    [Assembly Casing.SLDASM, Assembly Casing.x_t, Assembly.SLDASM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]
2024-10-01 code thoda thoda chl rha
    torque pura aa rha but balance ni ho rha abhi
2024-10-13 Code and file Added
    [Assembly - Box-1.STL, Assembly - Side Support-1.STL, Assembly - Side Support-2.STL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]
2024-10-15 Final CAD Updated
    [Casing Assemby.SLDASM, Final Rod.SLDPRT, Final Rod.STL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]
2024-10-15 POC Doc added
    [Top Plate.SLDPRT]
2024-10-20 added code for sir ka circuit and our circuit
    [CIRCUIT-DIAGRAM.fzz]
2024-12-21 Aluminum Model added
    [Battery.SLDPRT, Beaker Assembly.x_t, Flang.SLDPRT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]
2025-01-06 Al model update
    [Flang.SLDPRT, Low Plate Assembly.SLDASM, Low Plate.SLDPRT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]
2025-01-20 PCB FILES
2025-02-07 Folder updates
    [Assem3.SLDASM, Assembly - Box-1.STL, Assembly - Side Support-1.STL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]
2025-02-07 Unzip IR
    [TWSBR_withIR.kicad_pcb, TWSBR_withIR.kicad_sch, TWSBR_without_motor_driver.kicad_pcb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]
2025-05-09 file updates
    [CIRCUIT-DIAGRAM.fzz, TWSBR_withIR.kicad_pcb, TWSBR_withIR.kicad_sch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]
